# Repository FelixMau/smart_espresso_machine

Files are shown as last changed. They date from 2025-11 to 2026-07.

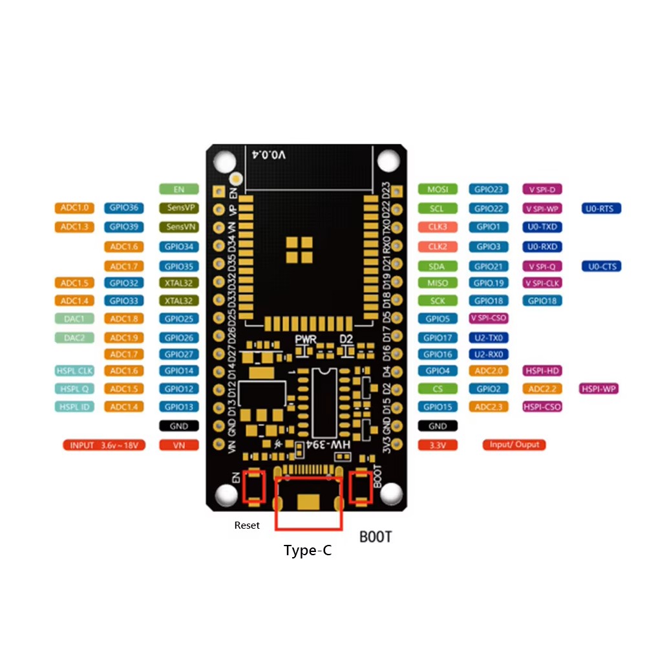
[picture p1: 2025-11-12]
Datenblätter/ESP_PINS.jpg

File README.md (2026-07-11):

# smart espresso machine

A hobby project to digitalise and IoT-enable my **Dalla Corte Mini** espresso machine (and maybe other machines in the future).

Unlike [Gaggiuino](https://gaggiuino.github.io/#/?id=home) or [GaggiMate](https://gaggimate.eu/), the goal here is **not** to replace the machine's original controls but to **extend** them. This way we don't have to mingle so much with high voltages, and the machine stays fully restorable to stock.

An ESP32 reads a Bluetooth scale and a pressure sensor, drives the pump via a PWM dimmer with a PID pressure controller, and uses linear regression to predict when a shot reaches its target weight — stopping extraction at the optimal moment. Everything is monitored and controlled live from a web dashboard on the LAN.

## How this compares to Gaggiuino & GaggiMate

Both projects turn cheap single-boiler machines (Gaggia Classic, Rancilio Silvia) into smart ones by taking over the heater, pump and steam control. This project serves a different niche:

| | Gaggiuino / GaggiMate | This project |
|---|---|---|
| Target machine | Single-boiler entry-level | Dual-boiler prosumer (Dalla Corte Mini) |
| Integration | Replaces the machine's controls | Extends them (opto-isolated button presses) — restorable to stock |
| Temperature & steam | PID heater + steam control | Not needed — the dual boiler already does this |
| Display | Installed touchscreen | Headless — a spare phone / any browser is the screen |
| Brew by weight | Yes | Yes, with regression-based predictive stop and auto-learned drip offset |
| Pressure profiling | Yes (Gaggiuino also flow) | Yes — time-based profiles with PID pump control |
| App integration | Beanconqueror (Gaggiuino) | Beanconqueror, via Gaggiuino-compatible API |

## Dashboard

Live monitoring, start/stop/reset, PID tuning, goal weight and pressure profile editing, plus live charts and a shot-history comparison — all served from the ESP32.

<!-- Add real screenshots to the assets/ folder (see assets/README.md) -->
Dashboard
Live shot

## Features

- [x] Connect the scale to the microcontroller
- [x] Microcontroller can read the *shot button* from the machine
- [x] Microcontroller is able to also 'press' the *shot button*
- [x] Design a PCB to hold the sensors
- [x] Microcontroller adjusts pump power via a dimmer
- [x] Mechanical knob to *manually* adjust pump power during shots
- [x] Add pressure sensor
- [x] PID-controlled pressure profiles (live-tunable over the web)
- [x] Predictive shot stopping via linear regression on weight-vs-time
- [x] EEPROM auto-learning of the weight offset after each shot
- [x] Async web dashboard: live tiles, charts, control and tuning
- [ ] Pressure sensor readings shown on a simple on-device display
- [ ] Design cases for PCB, display, knob
- [ ] Design import to beanconqueror -> custom machine
should be able to start shot via app
- [ ] Implement correct zero crosing detection and update pwm control accordingly
- [ ] Cleaning mode/cycle for descale and for detergent
- [ ] If no Wifi is available advertise own wifi and on it the webserver to do the same as on the local network
- [ ] Add another (manual)pressuresensor to evaluate accuracy of messurements, they sometimes feel a little off or I should adjust the expansionvalve

### Future tasks:

- [ ] Check on 230V safety and how to design properly with 230V on a espressomachine (that uses heats up water and puts it under pressure)
- [ ] Expose machine to internet? IDK this leads to many questions needing answeres such as how and which ports would need to be opened? Xiaomi robo cleaner does that somehow but I dont know how yet. Also password would be needed to log in -> or some local setup would provide a "password" via the app internally but all of this seems like a hustle for just the little benefit of no need to connect to local wifi....
- [ ] How could I sense the watertank fill status?

## Working details

- **Scale**: Acaia Lunar, via [@tatemazer's AcaiaArduinoBLE](https://github.com/tatemazer/AcaiaArduinoBLE) library.
- **Microcontroller**: ESP32 (upesy_wroom), firmware built with PlatformIO.
- **Button read/write**: via optocouplers, so the ESP never touches the machine's high-voltage logic.
- **Pump control**: PWM signal to the dimmer (zero-crossing functionality not yet working).
- **Manual override**: an encoder knob controls pump power (handy while work is in progress).
- **Architecture**: separate FreeRTOS tasks for BLE, the control loop, and the web server, so a missing scale or busy web client can never stall brewing. Boots and brews without WiFi and without the scale.

## Getting started

```bash
# 1. Provide WiFi credentials (this file is gitignored — never commit it)
cp src/secrets.h.example src/secrets.h   # then edit ssid / password

# 2. Build and upload
platformio run -e upesy_wroom
platformio run -e upesy_wroom --target upload

# 3. Watch serial output (dashboard URL is printed periodically)
platformio device monitor
```

The dashboard is then reachable at the IP the ESP32 prints on the serial console.

## PCB

The KiCad design lives in `pcb/`. Latest revision:

- [x] Added lights / power connections
- [x] Corrected false routing
- [x] Corrected optocoupler footprints
- [x] Added on/off switch to save power on the ESP
- [x] Got a second opinion on the PCB design
- [x] Added interface for a potential display

## License

Licensed under the **GNU General Public License v3.0** — see [LICENSE](LICENSE).

Copyright © 2026 Felix Maurer.

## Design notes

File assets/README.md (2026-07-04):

# Media assets

Drop dashboard screenshots / GIF here so the README can display them:

- `dashboard.png` — main dashboard view (live tiles, charts)
- `dashboard.gif` — short screen recording of a live shot
- `pressure-profile.png` — pressure profile editor (optional)

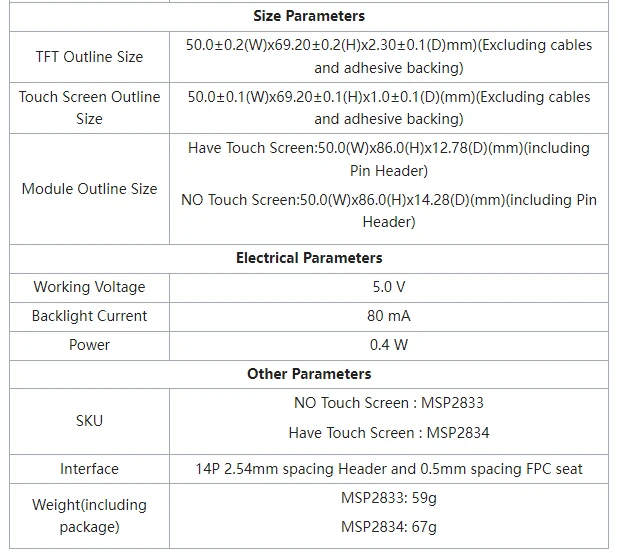
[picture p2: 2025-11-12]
Datenblätter/Display.webp

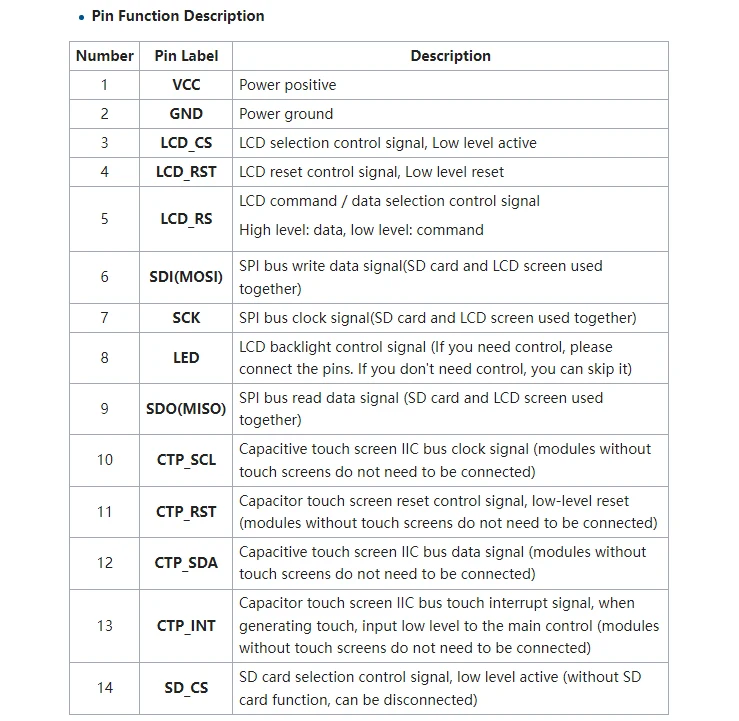
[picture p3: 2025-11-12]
Datenblätter/Pins_Display.webp

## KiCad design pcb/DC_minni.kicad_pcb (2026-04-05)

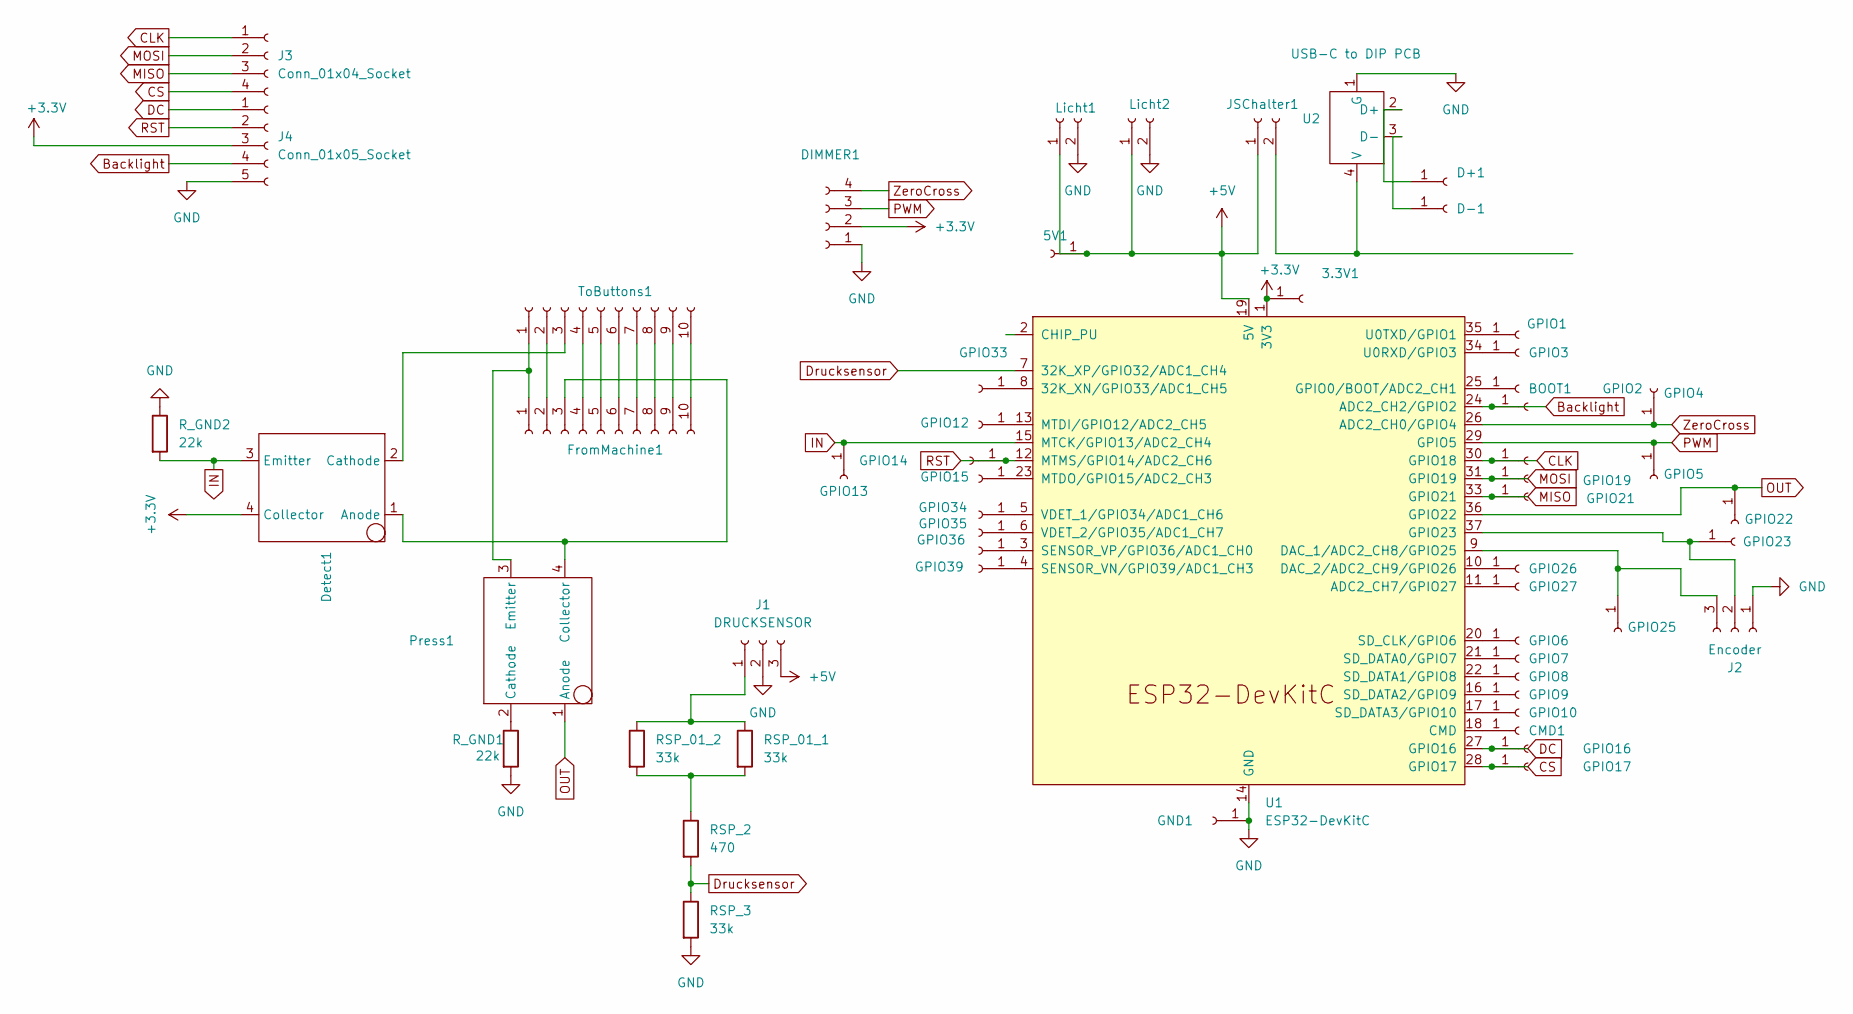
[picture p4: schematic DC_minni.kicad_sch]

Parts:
3.3V1, 5V1: Conn_01x01_Socket; PinHeader_1x01_P2.54mm_Vertical
BOOT1: Conn_01x01_Socket; PinHeader_1x01_P2.54mm_Vertical
CMD1: Conn_01x01_Socket; PinHeader_1x01_P2.54mm_Vertical
D+1: Conn_01x01_Socket; PinHeader_1x01_P2.54mm_Vertical
D-1: Conn_01x01_Socket; PinHeader_1x01_P2.54mm_Vertical
DIMMER1: Conn_01x04_Socket; JST_XH_B4B-XH-A_1x04_P2.50mm_Vertical
Detect1: HCPL-817
FromMachine1: Conn_01x10_Socket; IDC-Header_2x05_P2.54mm_Vertical
GND1: Conn_01x01_Socket; PinHeader_1x01_P2.54mm_Vertical
GPIO1, GPIO2, GPIO3, GPIO4, GPIO5, GPIO6, GPIO7, GPIO8, GPIO9, GPIO10, GPIO12, GPIO13, GPIO14, GPIO15, GPIO16, GPIO17, GPIO18, GPIO19, GPIO21, GPIO22, GPIO23, GPIO25, GPIO26, GPIO27, GPIO33, GPIO34, GPIO35, GPIO36, GPIO39: Conn_01x01_Socket; PinHeader_1x01_P2.54mm_Vertical
J1: DRUCKSENSOR; JST_XH_B3B-XH-A_1x03_P2.50mm_Vertical
J2: Encoder; JST_XH_B3B-XH-A_1x03_P2.50mm_Vertical
J3: Conn_01x04_Socket; JST_XH_B4B-XH-A_1x04_P2.50mm_Vertical
J4: Conn_01x05_Socket; JST_XH_B5B-XH-A_1x05_P2.50mm_Vertical
JSChalter1: Conn_01x02_Socket; JST_EH_B2B-EH-A_1x02_P2.50mm_Vertical
Licht1, Licht2: Conn_01x02_Socket; JST_EH_B2B-EH-A_1x02_P2.50mm_Vertical
Press1: HCPL-817
RSP_01_1, RSP_01_2, RSP_3: 33k; R_Axial_DIN0207_L6.3mm_D2.5mm_P10.16mm_Horizontal
RSP_2: 470; R_Axial_DIN0207_L6.3mm_D2.5mm_P10.16mm_Horizontal
R_GND1, R_GND2: 22k; R_Axial_DIN0207_L6.3mm_D2.5mm_P10.16mm_Horizontal
ToButtons1: Conn_01x10_Socket; IDC-Header_2x05_P2.54mm_Vertical
U1: ESP32-DevKitC
U2: USB-C to DIP PCB; USB-C zu DIP PCB

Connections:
+3.3V: 3.3V1.1, DIMMER1.2, Detect1.4 (Collector), J4.3, U1.1 (3V3); also elsewhere on the board
+5V: 5V1.1, J1.3, JSChalter1.1, Licht1.1, Licht2.1, U1.19 (5V)
Backlight: GPIO2.1, J4.4, U1.24 (ADC2_CH2/GPIO2)
CLK: GPIO18.1, J3.1, U1.30 (GPIO18)
CS: GPIO17.1, J3.4, U1.28 (GPIO17)
DC: GPIO16.1, J4.1, U1.27 (GPIO16)
Drucksensor: RSP_2.2, RSP_3.1, U1.7 (32K_XP/GPIO32/ADC1_CH4)
GND: DIMMER1.1, GND1.1, J1.2, J2.1, J4.5, Licht1.2, Licht2.2, RSP_3.2, R_GND1.2, R_GND2.1, U1.14 (GND), U1.32 (GND), U1.38 (GND), U2.1 (G); also elsewhere on the board
IN: Detect1.3 (Emitter), GPIO13.1, R_GND2.2, U1.15 (MTCK/GPIO13/ADC2_CH4); also elsewhere on the board
MISO: GPIO21.1, J3.3, U1.33 (GPIO21)
MOSI: GPIO19.1, J3.2, U1.31 (GPIO19)
unnamed: BOOT1.1, U1.25 (GPIO0/BOOT/ADC2_CH1)
unnamed: CMD1.1, U1.18 (CMD)
unnamed: D+1.1, U2.2 (D+)
unnamed: D-1.1, U2.3 (D-)
unnamed 15: Detect1.1 (Anode), FromMachine1.3, Press1.4 (Collector); also elsewhere on the board
unnamed 16: Detect1.2 (Cathode), ToButtons1.3; also elsewhere on the board
unnamed: FromMachine1.1, Press1.3 (Emitter), ToButtons1.1
unnamed: FromMachine1.2, ToButtons1.2
unnamed: FromMachine1.4, ToButtons1.4
unnamed: FromMachine1.5, ToButtons1.5
unnamed: FromMachine1.6, ToButtons1.6
unnamed: FromMachine1.7, ToButtons1.7
unnamed: FromMachine1.8, ToButtons1.8
unnamed: FromMachine1.9, ToButtons1.9
unnamed: FromMachine1.10, ToButtons1.10
unnamed: GPIO1.1, U1.35 (U0TXD/GPIO1)
unnamed: GPIO3.1, U1.34 (U0RXD/GPIO3)
unnamed: GPIO6.1, U1.20 (SD_CLK/GPIO6)
unnamed: GPIO7.1, U1.21 (SD_DATA0/GPIO7)
unnamed: GPIO8.1, U1.22 (SD_DATA1/GPIO8)
unnamed: GPIO9.1, U1.16 (SD_DATA2/GPIO9)
unnamed: GPIO10.1, U1.17 (SD_DATA3/GPIO10)
unnamed: GPIO12.1, U1.13 (MTDI/GPIO12/ADC2_CH5)
unnamed: GPIO15.1, U1.23 (MTDO/GPIO15/ADC2_CH3)
unnamed: GPIO23.1, J2.2, U1.37 (GPIO23)
unnamed: GPIO25.1, J2.3, U1.9 (DAC_1/ADC2_CH8/GPIO25)
unnamed: GPIO26.1, U1.10 (DAC_2/ADC2_CH9/GPIO26)
unnamed: GPIO27.1, U1.11 (ADC2_CH7/GPIO27)
unnamed: GPIO33.1, U1.8 (32K_XN/GPIO33/ADC1_CH5)
unnamed: GPIO34.1, U1.5 (VDET_1/GPIO34/ADC1_CH6)
unnamed: GPIO35.1, U1.6 (VDET_2/GPIO35/ADC1_CH7)
unnamed: GPIO36.1, U1.3 (SENSOR_VP/GPIO36/ADC1_CH0)
unnamed: GPIO39.1, U1.4 (SENSOR_VN/GPIO39/ADC1_CH3)
unnamed: J1.1, RSP_01_1.1, RSP_01_2.1
unnamed: JSChalter1.2, U2.4 (V)
unnamed: Press1.2 (Cathode), R_GND1.1
unnamed: RSP_01_1.2, RSP_01_2.2, RSP_2.1
OUT: GPIO22.1, Press1.1 (Anode), U1.36 (GPIO22); also elsewhere on the board
PWM: DIMMER1.3, GPIO5.1, U1.29 (GPIO5); also elsewhere on the board
RST: GPIO14.1, J4.2, U1.12 (MTMS/GPIO14/ADC2_CH6)
ZeroCross: DIMMER1.4, GPIO4.1, U1.26 (ADC2_CH0/GPIO4); also elsewhere on the board

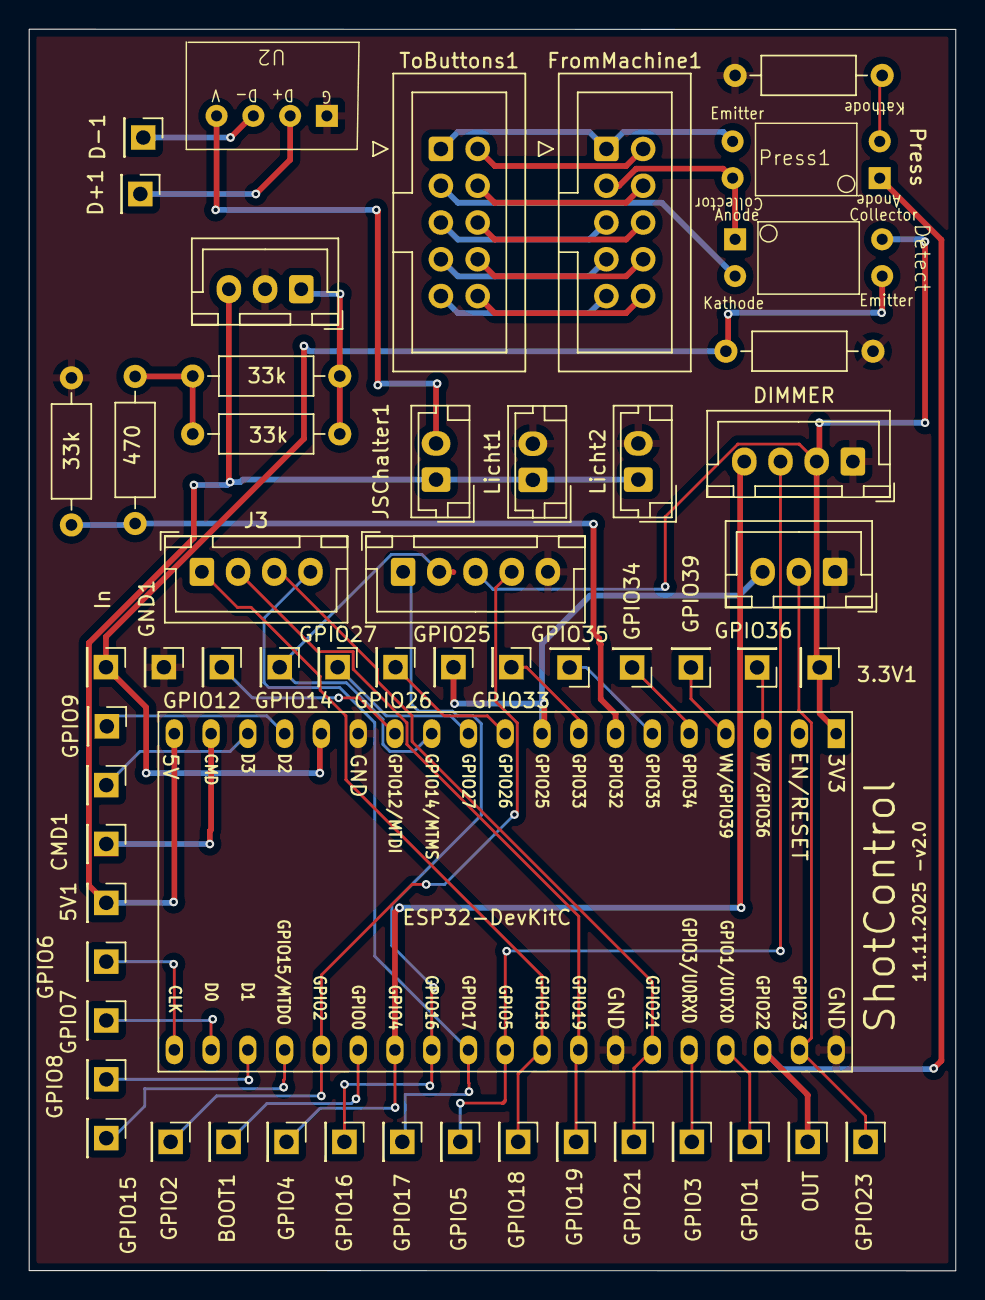
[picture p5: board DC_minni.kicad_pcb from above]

Board: 4 copper layers, 64.0 x 85.8 mm, 56 parts (0 on the bottom side), 52 nets.

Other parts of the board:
DIMMER: Conn_01x04_Socket; JST_XH_B4B-XH-A_1x04_P2.50mm_Vertical
Detect: HCPL-817
In: Conn_01x01_Socket; PinHeader_1x01_P2.54mm_Vertical
OUT: Conn_01x01_Socket; PinHeader_1x01_P2.54mm_Vertical

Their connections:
+3.3V: DIMMER.2, Detect.4 (Collector); also elsewhere on the board
GND: DIMMER.1; also elsewhere on the board
IN: Detect.3 (Emitter), In.1; also elsewhere on the board
unnamed 15: Detect.1 (Anode); also elsewhere on the board
unnamed 16: Detect.2 (Cathode); also elsewhere on the board
OUT: OUT.1; also elsewhere on the board
PWM: DIMMER.3; also elsewhere on the board
ZeroCross: DIMMER.4; also elsewhere on the board

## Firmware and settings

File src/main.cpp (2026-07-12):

#include <Arduino.h>
#include <ESP32Encoder.h>
#include <AcaiaArduinoBLE.h>
#include <WiFi.h>

#include "cleaning_cycle.h"
#include "debug.h"
#include "pid_controller.h"
#include "pump_dimmer.h"
#include "pump_model.h"
#include "settings.h"
#include "shot_history.h"
#include "shot_stopper.h"
#include "webserver.h"

// ============================================================================
// TESTING CONFIGURATION
// ============================================================================

#define TESTING_MODE_NO_SCALE false     // Set to true to disable scale/BLE connection during testing
#define TESTING_PRINT_SCALE_STATUS true // Print scale connection and pressure health status

// Pressure control law during shots: gaggiuino-style feedforward from the
// pump model (pump_model.cpp, needs PUMP_PSM_MODE for click counting) or the
// classic PID (pid_controller.cpp, /set_pid stays functional either way)
#define GAGGIUINO_PUMP_CONTROL true

// Window for the click-rate flow estimate and dP/dt (10 windows/s; clicks
// per window 0-5, EMA-smoothed on top)
#define DERIVED_STATE_PERIOD_MS 100

// ============================================================================
// PIN CONFIGURATION
// ============================================================================
// Button input, button output (PRESS_BUTTON_PIN, GPIO 22) and the pressure
// sensor (PRESSURE_PIN, GPIO 32) are defined in shot_stopper.h.

// Encoder pins (half-quad mode)
const int ENCODER_PIN_A = 23;
const int ENCODER_PIN_B = 25;

// Pump dimmer: phase-angle control in pump_dimmer.cpp. Triac gate on
// DIMMER_PIN, mains zero-cross detector on ZERO_CROSS_PIN (GPIO 4).
const int DIMMER_PIN = 5;  // Triac gate / opto-coupler drive

// Display SPI pins (for future display integration)
const int TFT_CLK = 18;   // SPI clock
const int TFT_MOSI = 19;  // SPI data out to display
const int TFT_MISO = 21;  // SPI data in from display
const int TFT_CS = 17;    // Chip select
const int TFT_DC = 16;    // Data/command
const int TFT_RST = 14;   // Reset
const int TFT_BL = 2;     // Backlight PWM (future)

// ============================================================================
// GLOBAL STATE
// ============================================================================
// 'shot' and 'currentWeight' are defined in shot_stopper.cpp: currentWeight
// is written by the scale task, read by the control task and web server.

ESP32Encoder encoder;

// PID controller for pressure regulation, live-tunable via the web dashboard.
// Gentler defaults than the original 25/0.5/8: with the measurement now
// sampled at 20 Hz and the derivative filtered, less gain is needed and the
// old values limit-cycled (+/-2-3 bar swings every few seconds).
PIDController pressurePID(15.0f, 1.0f, 5.0f);

// Real-time control loop task (defined below), started from setup()
void controlTask(void* param);
// Background scale connection/polling task (defined below), started from setup()
void scaleTask(void* param);

// ============================================================================
// SETUP
// ============================================================================

void setup() {
  // CPU and serial configuration
  // 240 MHz: WiFi (web server) + BLE (scale) share the radio and need headroom
  setCpuFrequencyMhz(240);
  // 115200: at 9600 the per-iteration debug lines took longer to transmit
  // than a control iteration, and the blocked Serial writes throttled the
  // control loop to ~6 Hz
  Serial.begin(115200);
  delay(100);
  DEBUG_STARTUP_PRINT("========================================");
  DEBUG_STARTUP_PRINT("Smart Espresso Machine Starting");
  DEBUG_STARTUP_PRINT("========================================");

  // Load persisted settings (goal weight, offset, pressure profile, cleaning
  // config, WiFi credentials) from EEPROM and apply them to the live state.
  // Must run before the tasks start and before initializeWiFi().
  settingsLoad();

  // GPIO pin initialization
  pinMode(LED_BUILTIN, OUTPUT);
  pinMode(BUTTON_INPUT_PIN, INPUT_PULLUP);  // Button input
  pinMode(PRESS_BUTTON_PIN, OUTPUT);        // Button output (opto-isolated)

  // Display pins (for future display integration)
  pinMode(TFT_CLK, OUTPUT);
  pinMode(TFT_MOSI, OUTPUT);
  pinMode(TFT_MISO, INPUT);
  pinMode(TFT_CS, OUTPUT);
  pinMode(TFT_DC, OUTPUT);
  pinMode(TFT_RST, OUTPUT);
  pinMode(TFT_BL, OUTPUT);
  DEBUG_STARTUP_PRINT("Display pins configured (ready for SPI display)");

  // Initialize encoder (half-quad mode for 2-pin configuration)
  encoder.attachHalfQuad(ENCODER_PIN_A, ENCODER_PIN_B);
  encoder.setCount(0);
  DEBUG_STARTUP_PRINT("Encoder initialized (half-quad mode)");

  // Initialize the phase-angle pump dimmer (zero-cross synced triac control).
  // Power level starts at 255, so the pump runs at 100% from the first
  // detected zero crossing (idle state).
  initPumpDimmer(DIMMER_PIN);
  DEBUG_STARTUP_PRINT("Phase-angle dimmer initialized (zero cross on GPIO %d) - Pump at 100%% (idle)",
                      ZERO_CROSS_PIN);

  #if !TESTING_MODE_NO_SCALE
  // BLE initialization (for Acaia Lunar scale connection)
  BLE.begin();
  BLE.setLocalName("shotStopper");
  DEBUG_STARTUP_PRINT("Bluetooth initialized for scale connection");
  #else
  DEBUG_STARTUP_PRINT("TESTING MODE: Scale/BLE connection disabled");
  scaleConnected = true;  // Pretend connected so the dashboard start button works
  #endif

  // Shot history buffer (RAM-only, read by the web server)
  initShotHistory();

  // WiFi and web server (LAN dashboard). Boot continues without the
  // dashboard if WiFi is unavailable (15s timeout).
  if (initializeWiFi()) {
    initializeServer(&pressurePID);
  }

  // Run the real-time control loop as its own FreeRTOS task on core 1 with
  // priority above loopTask, so the async web server (core 0) and anything
  // in loop() can never stall scale polling, trajectory updates, or pump PWM.
  xTaskCreatePinnedToCore(controlTask, "control", 10240, nullptr, 2, nullptr, 1);

  #if !TESTING_MODE_NO_SCALE
  // Scale connection runs as a background task at priority 1 (below the
  // control task) so a missing scale can never stall brewing logic or the
  // web dashboard. Core 1: the task-watchdogged core-0 idle task must not
  // be starved by the blocking 10 s BLE scan inside scale.init().
  xTaskCreatePinnedToCore(scaleTask, "scale", 8192, nullptr, 1, nullptr, 1);
  #endif

  DEBUG_STARTUP_PRINT("Setup Complete");
}

// ============================================================================
// STATUS LOGGING
// ============================================================================

void printScalePressureStatus() {
  static unsigned long lastStatusMs = 0;
  if (!TESTING_PRINT_SCALE_STATUS) {
    return;
  }
  if (millis() - lastStatusMs < 1000) {
    return;
  }
  lastStatusMs = millis();

  int raw = analogRead(PRESSURE_PIN);
  float voltage = raw * (3.3f / 4095.0f);
  float pressure = pressureBarFromVoltage(voltage);
  DEBUG_SENSOR_PRINT("Pressure raw: %d | voltage: %.2f V | pressure: %.2f bar",
                     raw, voltage, pressure);
}

// Re-print the dashboard URL every 10s so it can't scroll away in the log
void printWifiStatus() {
  static unsigned long lastWifiStatusMs = 0;
  if (millis() - lastWifiStatusMs < 10000) {
    return;
  }
  lastWifiStatusMs = millis();
  if (WiFi.status() == WL_CONNECTED) {
    DEBUG_STARTUP_PRINT("Dashboard: http://%s/", WiFi.localIP().toString().c_str());
  } else {
    DEBUG_STARTUP_PRINT("WiFi not connected - dashboard unavailable");
  }
}

// ============================================================================
// CONTROL LOOP: Real-time control iteration
// ============================================================================
// Runs in its own FreeRTOS task (core 1, priority 2) so the async web server
// on core 0 can never stall scale polling, trajectory updates, or pump PWM.

void controlIteration() {
  // ========================================================================
  // PRESSURE SAMPLING (every iteration, ~20 Hz)
  // ========================================================================
  // The PID below must never act on a stale reading: sampling only at the
  // scale's ~2 Hz weight rate made the measurement jump between control
  // iterations, and the derivative term slammed the pump rail-to-rail on
  // every jump (the root cause of "jumpy" pressure).

  updatePressureSensor(&shot);

  // Derived state for the feedforward control law: dP/dt of the filtered
  // pressure, and the model-estimated pump flow from the PSM click counter
  // (one conducted mains cycle = one pump stroke). Computed over a 100 ms
  // window - per-iteration click deltas at 100 Hz would only ever be 0 or 1
  // and quantize the flow estimate to useless extremes.
  static unsigned long lastDerivedMs = 0;
  static uint32_t lastClickCount = 0;
  static float lastPressure = 0.0f;
  static float pressureChangeSpeed = 0.0f;
  static float smoothedPumpFlow = 0.0f;

  unsigned long nowMs = millis();
  if (lastDerivedMs == 0) {
    lastDerivedMs = nowMs;
    lastPressure = shot.pressure;
    lastClickCount = pumpDimmerClickCount();
  } else if (nowMs - lastDerivedMs >= DERIVED_STATE_PERIOD_MS) {
    float dt = (nowMs - lastDerivedMs) / 1000.0f;
    pressureChangeSpeed = (shot.pressure - lastPressure) / dt;

    uint32_t clicks = pumpDimmerClickCount();
    float clicksPerSecond = (clicks - lastClickCount) / dt;
    lastClickCount = clicks;
    float flow = getPumpFlow(clicksPerSecond, shot.pressure);
    smoothedPumpFlow += PUMP_FLOW_FILTER_ALPHA * (flow - smoothedPumpFlow);
    shot.pumpFlow = smoothedPumpFlow;

    lastPressure = shot.pressure;
    lastDerivedMs = nowMs;
  }

  // ========================================================================
  // SCALE CONNECTION AND DATA POLLING
  // ========================================================================

  #if !TESTING_MODE_NO_SCALE
  // Scale connection/polling is handled by scaleTask in the background;
  // this task never blocks on BLE and just consumes the shared state.
  if (!scaleConnected) {
    // Discard stale dashboard start clicks so a shot can't fire the moment
    // the scale reconnects
    webStartRequest = false;
    if (shot.brewing) {
      DEBUG_SHOT_PRINT("Scale disconnected during shot - ending shot (machine button untouched)");
      shot.brewing = false;
      setBrewingState(false);
    }
  } else if (scaleNewWeight) {
    scaleNewWeight = false;

    DEBUG_SCALE_PRINT("Weight: %.1f g | Offset: %.1f g", currentWeight, shot.weightOffset);

    // Update shot trajectory with new weight datapoint
    updateShotTrajectory(&shot, currentWeight);
  }
  #else
  // TESTING MODE: Skip scale connection and keep current weight at 0
  currentWeight = 0;
  #endif

  // ========================================================================
  // WEB DASHBOARD START/STOP REQUESTS
  // ========================================================================
  // HTTP handlers only set flags; the scale/BLE is touched exclusively here
  // in the control task.

  if (webStartRequest) {
    webStartRequest = false;
    if (!shot.brewing && !cleaningActive()) {
      DEBUG_SHOT_PRINT("Shot start requested via web - pressing machine button");
      if (MOMENTARY) {
        // Pulse the opto-coupled button to start the machine
        digitalWrite(PRESS_BUTTON_PIN, HIGH);
        delay(1000);
        digitalWrite(PRESS_BUTTON_PIN, LOW);
      } else {
        // Latching machine: hold the brew line via the output pin
        digitalWrite(PRESS_BUTTON_PIN, HIGH);
        buttonLatched = true;
      }
      shot.brewing = true;
      setBrewingState(true);
    }
  }
  if (webStopRequest) {
    webStopRequest = false;
    if (shot.brewing) {
      DEBUG_SHOT_PRINT("Shot stop requested via web - pressing machine button");
      shot.brewing = false;
      shot.end = EndType::WEB;  // Pulses the machine button like WEIGHT/TIME
      setBrewingState(false);
    }
  }
  if (webResetRequest) {
    webResetRequest = false;
    if (shot.brewing) {
      DEBUG_SHOT_PRINT("Shot reset requested via web - machine button untouched");
      shot.brewing = false;
      shot.end = EndType::BUTTON;  // BUTTON end skips the machine pulse
      setBrewingState(false);
    }
  }

  // ========================================================================
  // CLEANING CYCLE (automated detergent backflush, cleaning_cycle.cpp)
  // ========================================================================
  // Runs only when no shot is active; presses the machine button itself and
  // dictates the pump level below while active.

  cleaningUpdate(shot.pressure);

  // ========================================================================
  // PUMP DIMMER CONTROL (PID during shot, 100% when idle)
  // ========================================================================

  long encoderPosition = encoder.getCount();

  int pwmValue = 255;
  if (cleaningActive()) {
    // Full power while pressurizing, dimmed while holding at max pressure
    pwmValue = cleaningPumpLevel();
  } else if (!shot.brewing) {
    // IDLE STATE: Pump at full speed (100% = 255)
    pwmValue = 255;
  } else if (shot.datapoints == 0) {
    // Shot just started, no pressure data yet - reset PID and run full power
    pressurePID.reset();
    pwmValue = 255;
    DEBUG_ENCODER_PRINT("BREWING - waiting for pressure data, PWM: %d", pwmValue);
  } else {
    // BREWING STATE: pressure regulation
    float goalPressure = shot.currentGoalPressure;
    #if GAGGIUINO_PUMP_CONTROL
    // Feedforward from the pump model plus proportional trim (pump_model.cpp)
    float pct = getPumpPct(goalPressure, 0.0f, shot.pressure,
                           smoothedPumpFlow, pressureChangeSpeed);
    pwmValue = (int)roundf(pct * 255.0f);
    DEBUG_ENCODER_PRINT("BREWING - target %.1f bar, current %.1f bar, flow %.2f ml/s, PWM: %d",
                        goalPressure, shot.pressure, smoothedPumpFlow, pwmValue);
    #else
    pwmValue = pressurePID.calculate(goalPressure, shot.pressure);
    DEBUG_ENCODER_PRINT("BREWING - target %.1f bar, current %.1f bar, PWM: %d",
                        goalPressure, shot.pressure, pwmValue);
    #endif
  }

  DEBUG_ENCODER_PRINT("Encoder count: %ld | PWM output: %d", encoderPosition, pwmValue);
  if (!shot.brewing) {
    DEBUG_ENCODER_PRINT("IDLE - Pump at 100%% (255) | Encoder: %ld", encoderPosition);
  }

  // Apply final power level to the phase-angle dimmer and publish it for
  // the web dashboard
  pumpDimmerSetPower(pwmValue);
  shot.pumpPwm = pwmValue;

  // ========================================================================
  // BUTTON AND SHOT STATE MANAGEMENT
  // ========================================================================

  // Handle button state machine (debounced, machine-agnostic)
  handleButtonLogic();

  printScalePressureStatus();
  printWifiStatus();

  // Monitor for maximum shot duration (safety timeout)
  handleMaxDurationReached(&shot);

  // Detect shot end conditions (weight target, time limit, button release)
  handleShotEnd(&shot, currentWeight);

  // Post-shot error detection and EEPROM learning
  // Learns weight offset if final weight is within 5g of goal
  detectShotError(&shot, currentWeight);
}

// Control task: run the control iteration at a fixed ~10 ms cadence (100 Hz,
// gaggiuino's ballpark) so the pump level updates every mains cycle or two
// and the PSM pattern stays finely interleaved instead of bursting.
// The web server runs asynchronously in the AsyncTCP task and never blocks this.
void controlTask(void* param) {
  for (;;) {
    controlIteration();
    vTaskDelay(pdMS_TO_TICKS(10));
  }
}

// ============================================================================
// SCALE TASK: background BLE connection management and weight polling
// ============================================================================
// Owns ALL scale/BLE calls; everyone else talks to it via the flags in
// shot_stopper.h. scale.init() blocks up to 10 s while scanning - fine here,
// the control task and web server keep running. Between failed attempts the
// scan is stopped and the task backs off, because BLE scanning and WiFi share
// the one 2.4 GHz radio: scanning back-to-back starves WiFi until it drops.

#define SCALE_RETRY_BACKOFF_MS 5000

void scaleTask(void* param) {
  for (;;) {
    if (!scale.isConnected()) {
      scaleConnected = false;
      currentWeight = 0;
      // Drop commands queued while disconnected: they belong to a dead shot
      scaleStartSequenceRequest = false;
      scaleStopTimerRequest = false;
      scaleTareRequest = false;

      if (!scale.init()) {
        BLE.stopScan();  // init() leaves the scan running on timeout
        vTaskDelay(pdMS_TO_TICKS(SCALE_RETRY_BACKOFF_MS));
        continue;
      }
      DEBUG_SCALE_PRINT("Scale connected");
    }
    scaleConnected = true;

    // Heartbeat every ~30 s keeps the BLE connection alive
    if (scale.heartbeatRequired()) {
      scale.heartbeat();
    }

    // Poll continuously; without this the connection goes stale
    if (scale.newWeightAvailable()) {
      currentWeight = scale.getWeight();
      scaleNewWeight = true;
    }

    // Execute commands queued by the control task
    if (scaleStartSequenceRequest) {
      scaleStartSequenceRequest = false;
      scale.resetTimer();
      vTaskDelay(pdMS_TO_TICKS(50));  // Let the scale process each command
      scale.startTimer();
      if (AUTOTARE) {
        vTaskDelay(pdMS_TO_TICKS(50));
        scale.tare();
      }
    }
    if (scaleStopTimerRequest) {
      scaleStopTimerRequest = false;
      scale.stopTimer();
    }
    if (scaleTareRequest) {
      scaleTareRequest = false;
      scale.tare();
    }

    vTaskDelay(pdMS_TO_TICKS(20));
  }
}

// ============================================================================
// LOOP: WiFi watchdog - all real-time work happens in controlTask
// ============================================================================
// BLE scanning can knock WiFi off the shared radio; without this the
// dashboard never comes back once WiFi drops.

void loop() {
  static unsigned long lastWifiRetryMs = 0;
  if (webRebootRequest) {
    // Requested via /reboot (e.g. to apply new WiFi credentials); the handler
    // already refused it while brewing/cleaning. Short delay so the HTTP
    // response gets flushed before the restart.
    vTaskDelay(pdMS_TO_TICKS(500));
    ESP.restart();
  }
  if (WiFi.status() != WL_CONNECTED) {
    if (millis() - lastWifiRetryMs > 15000) {
      lastWifiRetryMs = millis();
      DEBUG_STARTUP_PRINT("WiFi down - attempting reconnect");
      WiFi.reconnect();
    }
  } else if (!serverStarted) {
    // WiFi came up after boot timed out - start the dashboard now
    initializeServer(&pressurePID);
  }
  vTaskDelay(pdMS_TO_TICKS(1000));
}

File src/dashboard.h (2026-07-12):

#ifndef DASHBOARD_H
#define DASHBOARD_H

// ============================================================================
// WEB DASHBOARD PAGE (served from PROGMEM at "/")
// ============================================================================
// Single-page dashboard: live tiles, start/stop, PID tuning sliders, goal
// weight / offset / pressure profile editors, live Chart.js plots and shot
// history. Chart.js is loaded from CDN (plan decision) - the page needs
// internet access on the client; the ESP itself never fetches it.
// Polls GET /state every 500 ms; history via /shots and /shot?id=N.

const char DASHBOARD_HTML[] PROGMEM = R"rawliteral(<!DOCTYPE html>
<html lang="en">
<head>
<meta charset="utf-8">
<meta name="viewport" content="width=device-width, initial-scale=1">
<title>Espresso Dashboard</title>
<script src="https://cdn.jsdelivr.net/npm/chart.js@4.4.9/dist/chart.umd.min.js"></script>
<style>
  :root {
    --page: #f9f9f7; --surface: #fcfcfb; --ink: #0b0b0b; --ink2: #52514e;
    --muted: #898781; --grid: #e1e0d9; --border: rgba(11,11,11,0.10);
    --accent: #2a78d6; --good: #0ca30c; --critical: #d03b3b;
  }
  @media (prefers-color-scheme: dark) {
    :root {
      --page: #0d0d0d; --surface: #1a1a19; --ink: #ffffff; --ink2: #c3c2b7;
      --muted: #898781; --grid: #2c2c2a; --border: rgba(255,255,255,0.10);
      --accent: #3987e5;
    }
  }
  * { box-sizing: border-box; }
  body {
    margin: 0; background: var(--page); color: var(--ink);
    font-family: system-ui, -apple-system, "Segoe UI", sans-serif;
  }
  header {
    display: flex; align-items: baseline; gap: 12px;
    padding: 14px 20px; border-bottom: 1px solid var(--border);
  }
  header h1 { font-size: 18px; margin: 0; }
  #conn { font-size: 13px; color: var(--muted); }
  #conn.ok { color: var(--good); }
  #conn.bad { color: var(--critical); }
  main { max-width: 1100px; margin: 0 auto; padding: 16px; }
  .cards { display: grid; grid-template-columns: repeat(auto-fit, minmax(130px, 1fr)); gap: 10px; }
  .card {
    background: var(--surface); border: 1px solid var(--border);
    border-radius: 10px; padding: 12px 14px;
  }
  .card .label { font-size: 12px; color: var(--muted); margin-bottom: 4px; }
  .card .value { font-size: 26px; font-weight: 600; }
  .card .sub { font-size: 12px; color: var(--ink2); margin-top: 2px; }
  section { margin-top: 20px; }
  section h2 { font-size: 14px; color: var(--ink2); margin: 0 0 10px; text-transform: uppercase; letter-spacing: 0.04em; }
  .panel { background: var(--surface); border: 1px solid var(--border); border-radius: 10px; padding: 14px; }
  .row { display: flex; flex-wrap: wrap; gap: 14px; align-items: center; }
  button {
    font: inherit; border: 1px solid var(--border); border-radius: 8px;
    padding: 10px 18px; cursor: pointer; background: var(--surface); color: var(--ink);
  }
  button.primary { background: var(--accent); border-color: var(--accent); color: #fff; }
  button.danger { background: var(--critical); border-color: var(--critical); color: #fff; }
  button:active { opacity: 0.8; }
  button:disabled { opacity: 0.4; cursor: not-allowed; }
  .value.ok { color: var(--good); }
  .value.bad { color: var(--critical); }
  input[type=number], input[type=text] {
    font: inherit; padding: 8px; border: 1px solid var(--border); border-radius: 8px;
    background: var(--page); color: var(--ink); width: 110px;
  }
  input.wide { width: 220px; }
  input[type=range] { width: 180px; accent-color: var(--accent); }
  .field { display: flex; flex-direction: column; gap: 4px; }
  .field label { font-size: 12px; color: var(--muted); }
  .slider-val { font-size: 13px; color: var(--ink2); min-width: 48px; display: inline-block; }
  .chartbox { position: relative; height: 220px; }
  table { border-collapse: collapse; width: 100%; font-size: 14px; }
  th, td { text-align: left; padding: 6px 10px; border-bottom: 1px solid var(--grid); }
  th { color: var(--muted); font-weight: 500; font-size: 12px; }
  td { color: var(--ink2); font-variant-numeric: tabular-nums; }
  .swatch { display: inline-block; width: 10px; height: 10px; border-radius: 3px; margin-right: 6px; }
  #histEmpty { color: var(--muted); font-size: 13px; }
</style>
</head>
<body>
<header>
  <h1>Espresso Dashboard</h1>
  <span id="conn">connecting…</span>
</header>
<main>
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

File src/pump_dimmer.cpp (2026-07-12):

#include "pump_dimmer.h"

#include "debug.h"

// ============================================================================
// TIMING CONSTANTS (50 Hz mains)
// ============================================================================

// One half-cycle, zero cross to zero cross: 10 ms at 50 Hz
static const uint32_t HALF_CYCLE_US = 10000;

// Zero-cross detectors ring/bounce around the crossing; edges arriving
// sooner than this after an accepted crossing are glitches, not crossings
static const uint32_t ZC_GLITCH_US = 4000;

// Never fire the gate closer than this to a zero crossing. Too early and the
// detector's pulse width blurs which half-cycle we are in; too late and the
// triac has no time to latch before the current stops again.
static const uint32_t MIN_FIRE_DELAY_US = 200;
static const uint32_t MAX_FIRE_DELAY_US = HALF_CYCLE_US - 500;

// Levels at the extremes skip the timer entirely: >= FULL_ON_LEVEL holds the
// gate high through the whole cycle, <= FULL_OFF_LEVEL never fires it
static const uint8_t FULL_ON_LEVEL = 250;
static const uint8_t FULL_OFF_LEVEL = 2;

// No crossing for this long means the sync signal is gone (10 missed
// half-cycles) - fall back to plain on/off control
static const uint32_t ZC_TIMEOUT_US = 100000;

// ============================================================================
// STATE
// ============================================================================

static int gatePin = -1;
static hw_timer_t* fireTimer = nullptr;

// Written by the control task, read by the zero-cross ISR (single byte, atomic)
static volatile uint8_t powerLevel = 255;

// Timestamp of the last accepted zero crossing (glitch filter + health check)
static volatile uint32_t lastZcUs = 0;

#if PUMP_PSM_MODE
// Bresenham accumulator: fire a cycle whenever it wraps past the full range,
// so any level 0-255 spreads its fired cycles as evenly as possible
static const uint16_t PSM_RANGE = 255;
static volatile uint16_t psmAccumulator = 0;
static volatile bool psmSecondHalf = false;   // Which half of the mains cycle
static volatile uint32_t psmClickCount = 0;   // Conducted cycles = pump strokes
#endif

// ============================================================================
// INTERRUPT HANDLERS
// ============================================================================

// Firing-delay timer expired: turn the triac on. The gate stays high until
// the next zero cross, so the triac keeps conducting even when the inductive
// pump load makes the current lag the voltage.
static void IRAM_ATTR onFireTimer() {
  digitalWrite(gatePin, HIGH);
}

// Mains zero crossing: drop the gate and arm the one-shot firing timer.
// Registered without the IRAM flag, so it is simply deferred during flash
// writes (EEPROM.commit) instead of crashing on the flash-resident timer HAL.
static void onZeroCross() {
  uint32_t now = micros();
  if (now - lastZcUs < ZC_GLITCH_US) {
    return;  // Ringing on the detector edge, not a real crossing
  }
  lastZcUs = now;

#if PUMP_PSM_MODE
  // The pump strokes once per full mains cycle (internal half-wave
  // rectification), so decide once per cycle and hold the gate through both
  // half-cycles; which polarity actually drives the coil doesn't matter.
  psmSecondHalf = !psmSecondHalf;
  if (psmSecondHalf) {
    return;
  }

  psmAccumulator += powerLevel;
  if (psmAccumulator >= PSM_RANGE) {
    psmAccumulator -= PSM_RANGE;
    digitalWrite(gatePin, HIGH);  // Conduct this cycle: one pump stroke
    psmClickCount++;
  } else {
    digitalWrite(gatePin, LOW);   // Skip this cycle
  }
  return;
#endif

  uint8_t level = powerLevel;
  if (level >= FULL_ON_LEVEL) {
    // Full power: hold the gate high, triac conducts the entire half-cycle
    digitalWrite(gatePin, HIGH);
    return;
  }

  digitalWrite(gatePin, LOW);  // Triac commutates off at the zero crossing
  if (level <= FULL_OFF_LEVEL) {
    return;  // Pump off: never fire this half-cycle
  }

  uint32_t delayUs = ((uint32_t)(255 - level) * HALF_CYCLE_US) / 255;
  delayUs = constrain(delayUs, MIN_FIRE_DELAY_US, MAX_FIRE_DELAY_US);

  timerRestart(fireTimer);
  timerAlarmWrite(fireTimer, delayUs, false);  // One-shot
  timerAlarmEnable(fireTimer);
}

// ============================================================================
// PUBLIC API
// ============================================================================

void initPumpDimmer(int pin) {
  gatePin = pin;
  pinMode(gatePin, OUTPUT);
  digitalWrite(gatePin, LOW);

  // Pull-up covers open-collector detector outputs; harmless for push-pull
  pinMode(ZERO_CROSS_PIN, INPUT_PULLUP);

  // Timer 0, 80 MHz / 80 = 1 tick per microsecond
  fireTimer = timerBegin(0, 80, true);
  timerAttachInterrupt(fireTimer, &onFireTimer, true);

  attachInterrupt(digitalPinToInterrupt(ZERO_CROSS_PIN), onZeroCross, RISING);

  DEBUG_PUMP_PRINT("%s dimmer initialized (gate GPIO %d, zero cross GPIO %d)",
                   PUMP_PSM_MODE ? "Pulse-skip (PSM)" : "Phase-angle",
                   gatePin, ZERO_CROSS_PIN);
}

bool pumpDimmerZcHealthy() {
  return (micros() - lastZcUs) < ZC_TIMEOUT_US;
}

uint32_t pumpDimmerClickCount() {
#if PUMP_PSM_MODE
  return psmClickCount;
#else
  return 0;
#endif
}

void pumpDimmerSetPower(uint8_t level) {
  powerLevel = level;

  // Log sync gain/loss once per transition (called from the control task)
  static bool wasHealthy = false;
  bool healthy = pumpDimmerZcHealthy();
  if (healthy != wasHealthy) {
    wasHealthy = healthy;
    if (healthy) {
      DEBUG_PUMP_PRINT("Zero-cross sync acquired - synced pump dimming active");
    } else {
      DEBUG_PUMP_PRINT("No zero crossings on GPIO %d - falling back to on/off pump control",
                       ZERO_CROSS_PIN);
    }
  }

  // Fallback when no zero crossings arrive (detector unplugged, bench setup
  // without mains): degrade to on/off so the pump never dies mid-shot. With a
  // random-fire opto-triac a solid HIGH gate means full conduction.
  if (!healthy) {
    digitalWrite(gatePin, level > FULL_OFF_LEVEL ? HIGH : LOW);
  }
}

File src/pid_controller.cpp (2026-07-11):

#include "pid_controller.h"

#include "debug.h"

PIDController::PIDController(float kp, float ki, float kd)
  : kp(kp), ki(ki), kd(kd),
    outputMin(0),   // 30% floor: min power to prevent backflow/pump shutoff
    outputMax(255),  // Full power maximum
    integralMax(100.0f),
    outputSlewRate(300.0f),
    integral(0.0f),
    previousMeasurement(0.0f),
    derivativeFiltered(0.0f),
    firstSample(true),
    lastTimeMs(0),
    lastPTerm(0.0f),
    lastITerm(0.0f),
    lastDTerm(0.0f),
    lastOutput(255) {}

void PIDController::reset() {
  integral = 0.0f;
  derivativeFiltered = 0.0f;
  firstSample = true;
  lastTimeMs = millis();
  lastPTerm = 0.0f;
  lastITerm = 0.0f;
  lastDTerm = 0.0f;
  lastOutput = outputMax;  // Pump idles at 100%; slew down from there at shot start
}

int PIDController::calculate(float setpoint, float measurement) {
  unsigned long now = millis();
  float dt = (now - lastTimeMs) / 1000.0f;  // Convert to seconds

  // Prevent division by zero on first call or very fast loops
  if (dt <= 0.0f || lastTimeMs == 0) {
    lastTimeMs = now;
    return outputMax;  // Default to full power on first call
  }

  // Calculate error (positive = need more pressure)
  float error = setpoint - measurement;

  // Proportional term
  float pTerm = kp * error;

  // Integral term with anti-windup clamping
  integral += error * dt;
  integral = constrain(integral, -integralMax, integralMax);
  float iTerm = ki * integral;

  // Derivative on measurement (sign-flipped), so setpoint steps from the
  // pressure profile don't kick the output; low-pass filtered against noise
  float derivative = firstSample ? 0.0f : -(measurement - previousMeasurement) / dt;
  firstSample = false;
  derivativeFiltered += PID_DERIVATIVE_FILTER_ALPHA * (derivative - derivativeFiltered);
  float dTerm = kd * derivativeFiltered;

  // Save state for next iteration
  previousMeasurement = measurement;
  lastTimeMs = now;

  // Calculate output: center at 128, add PID correction
  float output = 128.0f + pTerm + iTerm + dTerm;

  // Constrain to safe PWM range
  int pwmValue = constrain((int)round(output), outputMin, outputMax);

  // Slew-rate limit: ramp instead of jumping between power levels
  int maxStep = max(1, (int)(outputSlewRate * dt));
  pwmValue = constrain(pwmValue, lastOutput - maxStep, lastOutput + maxStep);
  pwmValue = constrain(pwmValue, outputMin, outputMax);

  // Store terms for external monitoring (web dashboard)
  lastPTerm = pTerm;
  lastITerm = iTerm;
  lastDTerm = dTerm;
  lastOutput = pwmValue;
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

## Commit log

2025-07-18 switch back buttons
2025-07-18 Adding additional debug serial prints.
2025-07-20 change pins back to as soldered
2025-07-29 Revert "Add goal weight update endpoint"
    [webserver.h]
2025-07-29 Add pressure profile update
2025-07-29 Handle negative times in pressure profile
2025-10-26 Add serial print
2025-10-26 NEw encoder lib
2025-11-09 Adding pcb
    [DC_minni-B_Mask.gbs, DC_minni-B_Paste.gbp, DC_minni-B_Silkscreen.gbo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]
2025-11-11 Shematic layout adjustments
    [DC_minni.kicad_sch]
2025-11-11 Endocer Pins switch to 23 and 25
2025-11-11 Add Encoder to Schematics
    [DC_minni.kicad_sch]
2025-11-11 Add Encoder to PCB, Update layout
    [DC_minni.kicad_pcb]
2025-11-11 Update PCB layout
2025-11-11 PCB routing
2025-11-11 Finished PCB routing
    [DC_minni.kicad_pcb]
2025-11-11 Implement comments from Review
    [DC_minni.kicad_pcb]
2025-11-12 Combining main and old main with claude
    [DC_minni.kicad_pcb, DC_minni.kicad_sch]
2025-11-12 Update README with project status
    Added a note about the project being on hold due to PCB printing costs.
2025-11-12 Adding Display Pins to main, adjust logic for auto dimmer & Encoder interaction
2025-11-17 Updated Pcb again
    [DC_minni.kicad_pcb, DC_minni.kicad_sch]
2026-04-05 update pressure pin
    [DC_minni-B_Mask.gbs, DC_minni-B_Paste.gbp, DC_minni-B_Silkscreen.gbo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]
2026-05-14 PID controller
2026-07-04 Applying Webserver upgrade, PID settings, live shot view, webbase start and stop, shot history
2026-07-04 Update claude scope and directories, as well as creating pitch.
2026-07-04 Remove work artifacts from repo (pitch checklist)
    Delete MAIN_CPP_UPDATES_SUMMARY.md, MAIN_CPP_QUICK_REFERENCE.txt,
    unused src/on_hold.h, and KiCad lock/backup files; ignore KiCad
    working files going forward.
2026-07-04 Add GPLv3 LICENSE and refresh README
    - Add full GPL-3.0 license text (project is now formally open source)
    - README: drop the 'on hold' note, document the web dashboard, PID
    pressure profiles and predictive stopping, add setup + license sections
    - Add assets/ folder with placeholders for dashboard screenshots/GIF
2026-07-05 Fix BQ integration and Pin number
    [main.cpp, shot_stopper.h, webserver.h]
2026-07-05 Refactor for C++ style guide: split modules into .h/.cpp, rename to conventions
    Restructure per the Makerguides C++ style guide for Arduino projects,
    behavior unchanged (verified: firmware builds, RAM/flash footprint equal):
    - Split header-only modules into declaration/implementation pairs:
    shot_stopper, shot_history, pid_controller, webserver now have .cpp
    files; headers hold types, extern declarations and prototypes only.
    shot_stopper.h gains its previously missing include guard.
    - Naming conventions: Shot/ShotRecord members and locals to camelCase
    (shot_timer -> shotTimer, ...), constants to UPPER_SNAKE
    (datapoints_trend_line -> TREND_LINE_DATAPOINTS, freq ->
    PWM_FREQUENCY_HZ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
    [debug.h, main.cpp, pid_controller.cpp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]
2026-07-05 Looking at kicad files
2026-07-11 Fix jumpy pressure: 20 Hz filtered sampling, smoother PID
    Shot data (ids 11-14) showed +/-2-3 bar limit cycling with a 2-8 s
    period. Root cause: the PID ran every 50 ms against a pressure value
    that was only refreshed at the scale's ~2 Hz weight rate, so the
    unfiltered derivative-on-error term kicked ~300 PWM counts whenever
    the stale reading jumped.
    - Sample the pressure sensor every control iteration (~20 Hz) with EMA
    smoothing instead of only on scale weight updates
    - Derivative on (filtered) measurement, so profile setpoint steps
    don't kick the output
    - Slew-rate limit the PWM output (outputSlewRate, default 300/s)
    - Gentler default gains: 25/0.5/8 -> 15/1/5 (live-tunable as before)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
    [main.cpp, pid_controller.cpp, shot_stopper.cpp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]
2026-07-11 Reset limit to 0
    [pid_controller.cpp]
2026-07-12 Gaggiunio pressure profiling
